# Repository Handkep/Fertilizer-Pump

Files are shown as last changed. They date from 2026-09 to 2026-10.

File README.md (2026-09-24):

# Automatic Fertilizer Dispenser

The fertilizer dispenser automatically doses fertilizer concentrates or stock solutions using one or more peristaltic pumps. The amount dispensed depends on the selected recipe and the intended irrigation water volume. After dosing, the pump and outlet tubing are flushed with water to help prevent salt deposits.

**Project status:** In development. The Peristaltic pump is currently in the prototyping phase. PCB design is in progress. The user interface and display are still to be determined.

## How It Works

Each recipe specifies a dose in ml per liter of irrigation water for each fertilizer. The required amount is calculated as follows:

```text
Fertilizer volume [ml] = Water volume [L] × Dose [ml/L]

Example: 10 L of water × 5 ml/L = 50 ml of fertilizer
```

A recipe can contain multiple fertilizers. Each fertilizer has its own separate channel, and the fertilizers are mixed only in the watering can. In the future, the device may support mixing fertilizers, after the pumps, to have a single outlet for the mixed solution. 

## Operation

The planned interface consists of a display and a rotary encoder with a push button:

1. **Set the water volume:** Turn the knob. Each detent increases the selected volume by 1 L.
2. **Confirm the volume:** Press the knob to proceed to recipe selection.
3. **Select a recipe:** Turn the knob to choose the desired recipe.
4. **Start dosing:** Press the knob again to dispense the fertilizer.

the further interface planning is still in progress. The display type has not yet been selected.

## Hardware

| Component | Planned configuration |
| --- | --- |
| Controller | ESP32-S3 |
| Channels | Four positions, initially only two populated with TMC2209 modules |
| Motor drivers | Plug-in TMC2209 StepStick modules |
| Driver control | STEP/DIR/EN and UART |
| Pumps | Custom stepper-driven peristaltic pumps, designed in Onshape |
| Motors | NEMA17 stepper motors |
| User interface | Rotary encoder with push button and a display |
| Display | To be selected: a small OLED or another display type; no seven-segment display |
| Calibration | Individual steps-per-ml calibration for each pump |

## Power and USB

### V1

- Motor and solenoid valve operation requires USB-C PD or a separate 12 V power supply.
- USB-C provides data connectivity and firmware flashing.
- USB alone is intended to power the control electronics, including the ESP32-S3 and user interface. Motors and solenoid valves remain inactive without the 12 V supply. The 12 V supply should not be required for firmware flashing.
- USB Power Delivery is included in V1.

## Fluid Path and Flushing

Each fertilizer channel has a selector valve upstream of the pump:

```mermaid
flowchart LR
    fertilizer["Fertilizer concentrate<br/>or stock solution"] -->|Dosing| valve{"Selector valve"}
    water["Flush water"] -->|Flushing| valve
    valve --> pump(["Peristaltic pump"])
    pump -->|Outlet tubing| can["Watering can"]

    classDef fertilizerStyle fill:#dcfce7,stroke:#15803d,color:#14532d,stroke-width:2px;
    classDef waterStyle fill:#dbeafe,stroke:#2563eb,color:#1e3a8a,stroke-width:2px;
    classDef hardwareStyle fill:#f1f5f9,stroke:#64748b,color:#0f172a,stroke-width:2px;
    classDef outputStyle fill:#fef3c7,stroke:#d97706,color:#78350f,stroke-width:2px;

    class fertilizer fertilizerStyle;
    class water waterStyle;
    class valve,pump hardwareStyle;
    class can outputStyle;
    linkStyle 0 stroke:#15803d,stroke-width:2px;
    linkStyle 1 stroke:#2563eb,stroke-width:2px;
```

V1 will initially use an inexpensive electrically operated two-position solenoid selector valve.

After dosing, the valve switches to water to flush the pump and outlet tubing. The flushing water also flows into the watering can.

The additional flushing water is not included in the fertilizer dose calculation. For the intended use, this extra volume is considered small relative to the uncertainty of measuring the water volume in a watering can.

### Planned for V2

- "peristaltic" selector valve built out of a servo and a 3D-printed part.
    - The servo connector will already be included on the V1 PCB to simplify this future upgrade.

## Development Status

The operating concept, four channel positions with two initially populated motor drivers, and separate fertilizer paths have been defined.

Practical testing is still pending. The display has not yet been selected.

## Future Possibilities

- Release as an open-source project
- A PCB kit or complete DIY kit
- Accompanying project documentation on YouTube

## License

A license has not yet been selected.

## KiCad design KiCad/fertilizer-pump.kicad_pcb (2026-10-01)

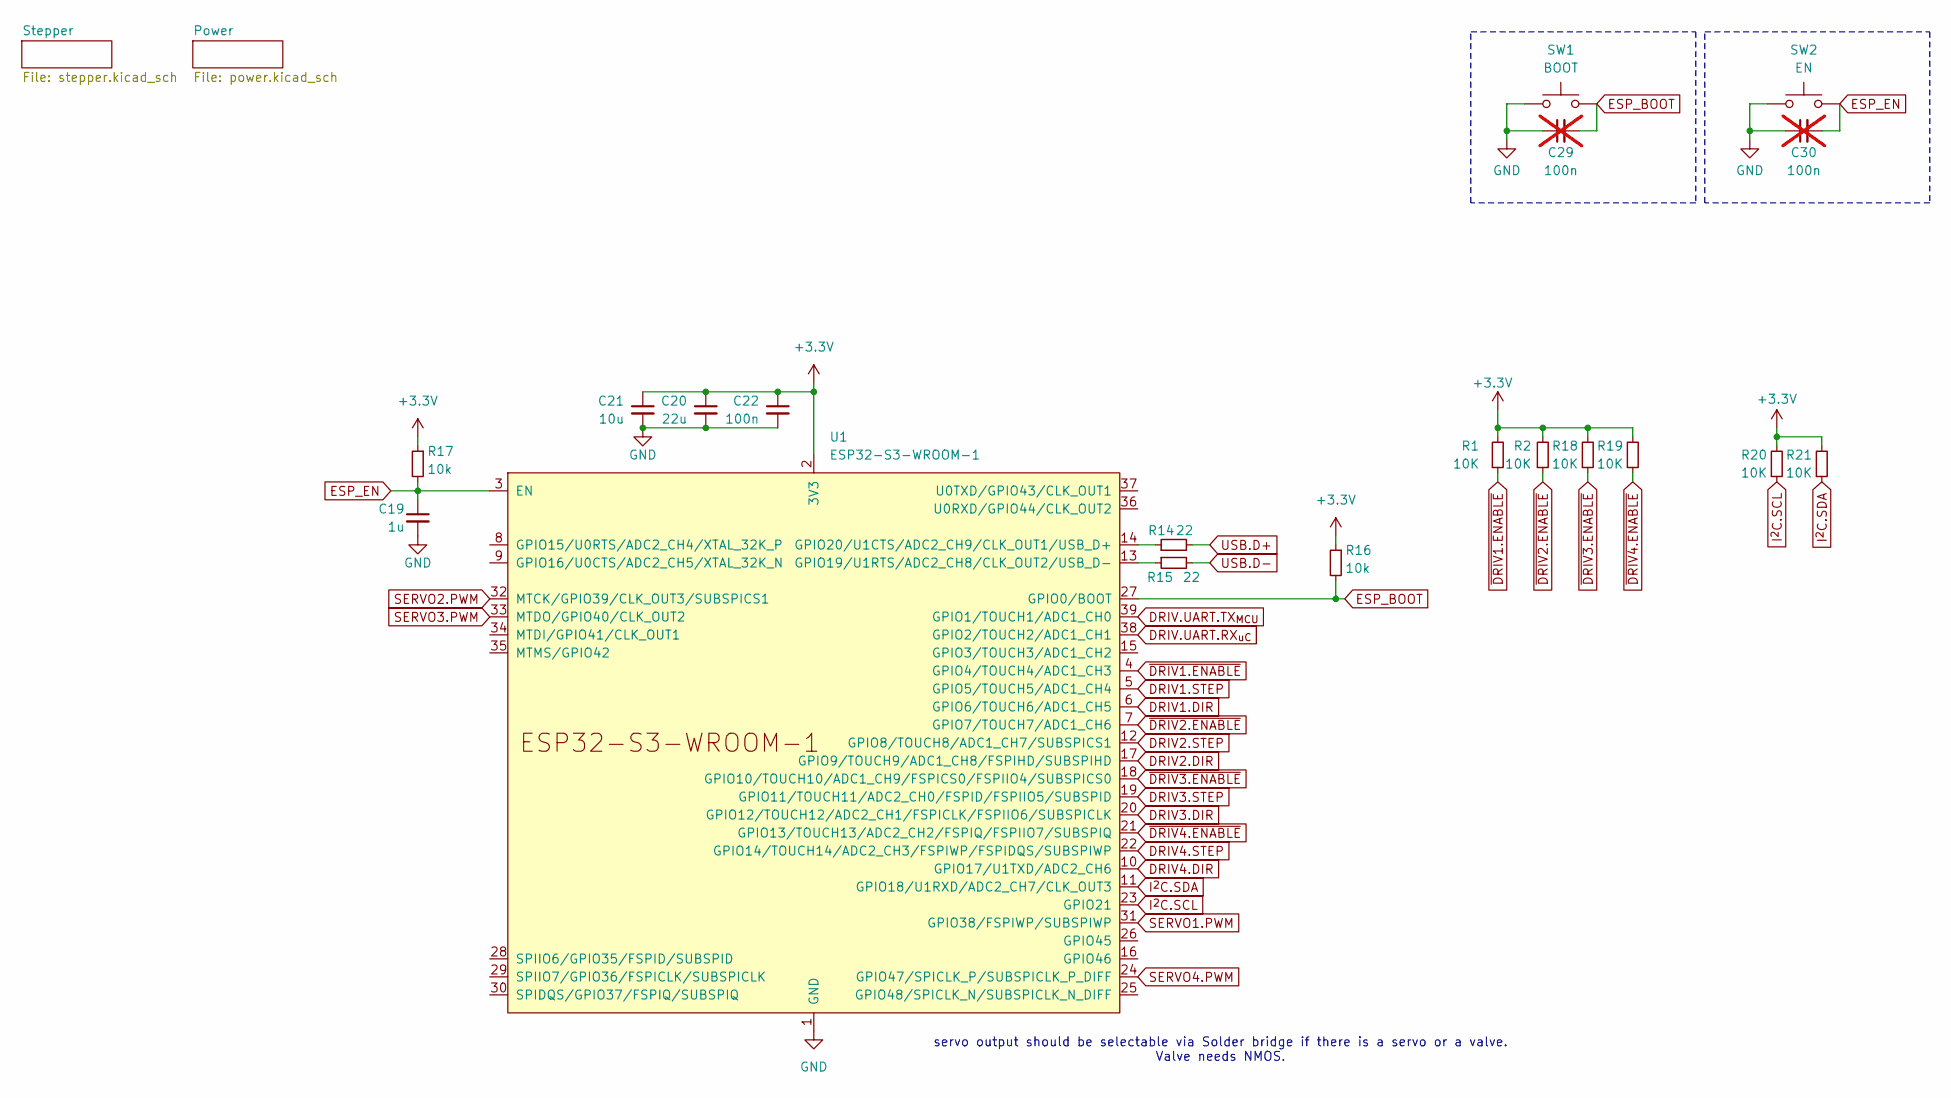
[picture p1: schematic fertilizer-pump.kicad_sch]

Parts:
C19: 1u; C_0805_2012Metric_Pad1.18x1.45mm_HandSolder; LCSC C303896
C20: 22u; C_0805_2012Metric_Pad1.18x1.45mm_HandSolder; LCSC C7432777
C21: 10u; C_0805_2012Metric_Pad1.18x1.45mm_HandSolder; LCSC C33546007
C22: 100n; C_0805_2012Metric_Pad1.18x1.45mm_HandSolder; LCSC C5137467
C29, C30: 100n; C_0805_2012Metric_Pad1.18x1.45mm_HandSolder; LCSC C5137467; not fitted
R1, R2, R18, R19, R20, R21: 10K; R_0805_2012Metric_Pad1.20x1.40mm_HandSolder; LCSC C2930231
R14, R15: 22; R_0805_2012Metric_Pad1.20x1.40mm_HandSolder
R16, R17: 10k; R_0805_2012Metric_Pad1.20x1.40mm_HandSolder; LCSC C2930231
SW1: BOOT; SHOU HAN TS342A2P-WZ; LCSC C557591
SW2: EN; SHOU HAN TS342A2P-WZ; LCSC C557591
U1: ESP32-S3-WROOM-1

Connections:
+3.3V: C20.1, C21.1, C22.1, R1.2, R2.2, R16.1, R17.1, R18.2, R19.2, R20.2, R21.2, U1.2 (3V3); also elsewhere on the board
DRIV1.DIR: U1.6 (GPIO6/TOUCH6/ADC1_CH5); also elsewhere on the board
DRIV1.STEP: U1.5 (GPIO5/TOUCH5/ADC1_CH4); also elsewhere on the board
DRIV2.DIR: U1.17 (GPIO9/TOUCH9/ADC1_CH8/FSPIHD/SUBSPIHD); also elsewhere on the board
DRIV2.STEP: U1.12 (GPIO8/TOUCH8/ADC1_CH7/SUBSPICS1); also elsewhere on the board
DRIV3.DIR: U1.20 (GPIO12/TOUCH12/ADC2_CH1/FSPICLK/FSPIIO6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); also elsewhere on the board
DRIV3.STEP: U1.19 (GPIO11/TOUCH11/ADC2_CH0/FSPID/FSPIIO5/S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); also elsewhere on the board
DRIV4.DIR: U1.10 (GPIO17/U1TXD/ADC2_CH6); also elsewhere on the board
DRIV4.STEP: U1.22 (GPIO14/TOUCH14/ADC2_CH3/FSPIWP/FSPIDQS/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); also elsewhere on the board
DRIV.UART: U1.38 (GPIO2/TOUCH2/ADC1_CH1); also elsewhere on the board
DRIV.UART.TX_{MCU}: U1.39 (GPIO1/TOUCH1/ADC1_CH0); also elsewhere on the board
ESP_BOOT: C29.2, R16.2, SW1.2, U1.27 (GPIO0/BOOT)
ESP_EN: C19.1, C30.2, R17.2, SW2.2, U1.3 (EN)
GND: C19.2, C20.2, C21.2, C22.2, C29.1, C30.1, SW1.1, SW2.1, U1.1 (GND), U1.40 (GND), U1.41 (GND); also elsewhere on the board
I^{2}C.SCL: R20.1, U1.23 (GPIO21); also elsewhere on the board
I^{2}C.SDA: R21.1, U1.11 (GPIO18/U1RXD/ADC2_CH7/CLK_OUT3); also elsewhere on the board
unnamed: R15.1, U1.13 (GPIO19/U1RTS/ADC2_CH8/CLK_OUT2/USB_D-)
unnamed: R14.1, U1.14 (GPIO20/U1CTS/ADC2_CH9/CLK_OUT1/USB_D+)
SERVO1.PWM: U1.31 (GPIO38/FSPIWP/SUBSPIWP); also elsewhere on the board
SERVO2.PWM: U1.32 (MTCK/GPIO39/CLK_OUT3/SUBSPICS1); also elsewhere on the board
SERVO3.PWM: U1.33 (MTDO/GPIO40/CLK_OUT2); also elsewhere on the board
SERVO4.PWM: U1.24 (GPIO47/SPICLK_P/SUBSPICLK_P_DIFF); also elsewhere on the board
USB.D+: R14.2; also elsewhere on the board
USB.D-: R15.2; also elsewhere on the board
~DRIV1.ENABLE: R1.1, U1.4 (GPIO4/TOUCH4/ADC1_CH3); also elsewhere on the board
~DRIV2.ENABLE: R2.1, U1.7 (GPIO7/TOUCH7/ADC1_CH6); also elsewhere on the board
~DRIV3.ENABLE: R18.1, U1.18 (GPIO10/TOUCH10/ADC1_CH9/FSPICS0/FSPIIO4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); also elsewhere on the board
~DRIV4.ENABLE: R19.1, U1.21 (GPIO13/TOUCH13/ADC2_CH2/FSPIQ/FSPIIO7/S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); also elsewhere on the board

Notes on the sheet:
servo output should be selectable via Solder bridge if there is a servo or a valve. Valve needs NMOS.

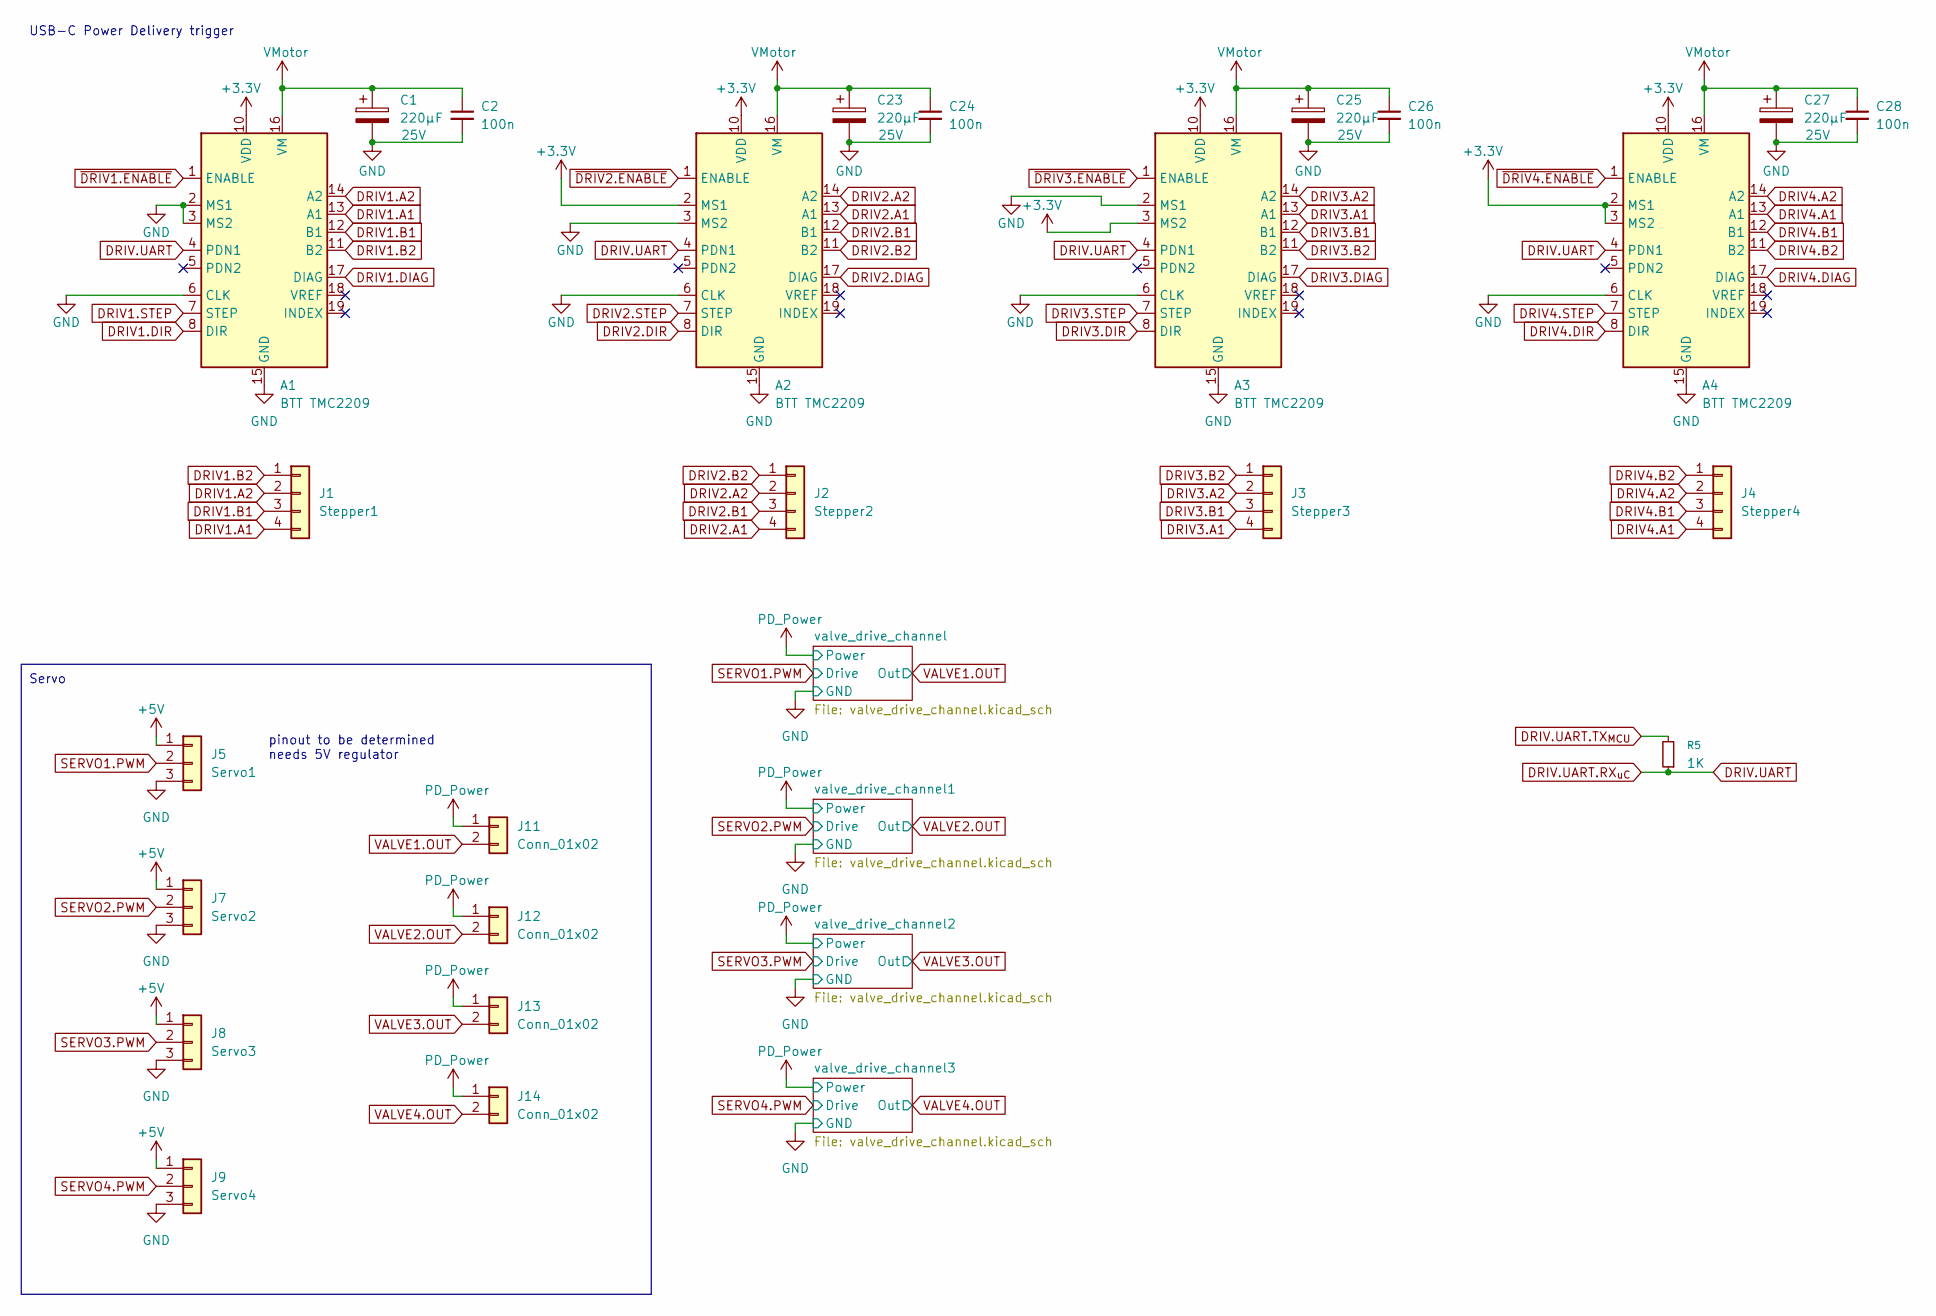
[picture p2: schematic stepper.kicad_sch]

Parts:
A1, A2, A3, A4: BTT TMC2209
C1, C23, C25, C27: 220µF; CP_Elec_6.3x7.7; Voltage 25V; LCSC C7471881
C2, C24, C26, C28: 100n; C_0805_2012Metric_Pad1.18x1.45mm_HandSolder; LCSC C48579601
J1: Stepper1; JST_XH_B4B-XH-A_1x04_P2.50mm_Vertical
J2: Stepper2; JST_XH_B4B-XH-A_1x04_P2.50mm_Vertical
J3: Stepper3; JST_XH_B4B-XH-A_1x04_P2.50mm_Vertical
J4: Stepper4; JST_XH_B4B-XH-A_1x04_P2.50mm_Vertical
J5: Servo1; JST_XH_B3B-XH-A_1x03_P2.50mm_Vertical
J7: Servo2; JST_XH_B3B-XH-A_1x03_P2.50mm_Vertical
J8: Servo3; JST_XH_B3B-XH-A_1x03_P2.50mm_Vertical
J9: Servo4; JST_XH_B3B-XH-A_1x03_P2.50mm_Vertical
J11, J12, J13, J14: Conn_01x02; JST_XH_B2B-XH-A_1x02_P2.50mm_Vertical
R5: 1K; R_0805_2012Metric_Pad1.20x1.40mm_HandSolder; LCSC C54921120

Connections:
+3.3V: A1.10 (VDD), A2.2 (MS1), A2.10 (VDD), A3.3 (MS2), A3.10 (VDD), A4.2 (MS1), A4.3 (MS2), A4.10 (VDD); also elsewhere on the board
+5V: J5.1, J7.1, J8.1, J9.1; also elsewhere on the board
DRIV1.A1: A1.13 (A1), J1.4
DRIV1.A2: A1.14 (A2), J1.2
DRIV1.B1: A1.12 (B1), J1.3
DRIV1.B2: A1.11 (B2), J1.1
DRIV1.DIAG: A1.17 (DIAG)
DRIV1.DIR: A1.8 (DIR); also elsewhere on the board
DRIV1.STEP: A1.7 (STEP); also elsewhere on the board
DRIV2.A1: A2.13 (A1), J2.4
DRIV2.A2: A2.14 (A2), J2.2
DRIV2.B1: A2.12 (B1), J2.3
DRIV2.B2: A2.11 (B2), J2.1
DRIV2.DIAG: A2.17 (DIAG)
DRIV2.DIR: A2.8 (DIR); also elsewhere on the board
DRIV2.STEP: A2.7 (STEP); also elsewhere on the board
DRIV3.A1: A3.13 (A1), J3.4
DRIV3.A2: A3.14 (A2), J3.2
DRIV3.B1: A3.12 (B1), J3.3
DRIV3.B2: A3.11 (B2), J3.1
DRIV3.DIAG: A3.17 (DIAG)
DRIV3.DIR: A3.8 (DIR); also elsewhere on the board
DRIV3.STEP: A3.7 (STEP); also elsewhere on the board
DRIV4.A1: A4.13 (A1), J4.4
DRIV4.A2: A4.14 (A2), J4.2
DRIV4.B1: A4.12 (B1), J4.3
DRIV4.B2: A4.11 (B2), J4.1
DRIV4.DIAG: A4.17 (DIAG)
DRIV4.DIR: A4.8 (DIR); also elsewhere on the board
DRIV4.STEP: A4.7 (STEP); also elsewhere on the board
DRIV.UART: A1.4 (PDN1), A2.4 (PDN1), A3.4 (PDN1), A4.4 (PDN1), R5.1; also elsewhere on the board
DRIV.UART.TX_{MCU}: R5.2; also elsewhere on the board
GND: A1.2 (MS1), A1.3 (MS2), A1.6 (CLK), A1.9 (GND), A1.15 (GND), A2.3 (MS2), A2.6 (CLK), A2.9 (GND), A2.15 (GND), A3.2 (MS1), A3.6 (CLK), A3.9 (GND), A3.15 (GND), A4.6 (CLK), A4.9 (GND), A4.15 (GND), C1.2, C2.2, C23.2, C24.2, C25.2, C26.2, C27.2, C28.2, J5.3, J7.3, J8.3, J9.3; also elsewhere on the board
PD_Power: J11.1, J12.1, J13.1, J14.1; also elsewhere on the board
SERVO1.PWM: J5.2; also elsewhere on the board
SERVO2.PWM: J7.2; also elsewhere on the board
SERVO3.PWM: J8.2; also elsewhere on the board
SERVO4.PWM: J9.2; also elsewhere on the board
VALVE1.OUT: J11.2; also elsewhere on the board
VALVE2.OUT: J12.2; also elsewhere on the board
VALVE3.OUT: J13.2; also elsewhere on the board
VALVE4.OUT: J14.2; also elsewhere on the board
VMotor: A1.16 (VM), A2.16 (VM), A3.16 (VM), A4.16 (VM), C1.1, C2.1, C23.1, C24.1, C25.1, C26.1, C27.1, C28.1; also elsewhere on the board
~DRIV1.ENABLE: A1.1 (ENABLE); also elsewhere on the board
~DRIV2.ENABLE: A2.1 (ENABLE); also elsewhere on the board
~DRIV3.ENABLE: A3.1 (ENABLE); also elsewhere on the board
~DRIV4.ENABLE: A4.1 (ENABLE); also elsewhere on the board

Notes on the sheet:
USB-C Power Delivery trigger
Servo
pinout to be determined needs 5V regulator

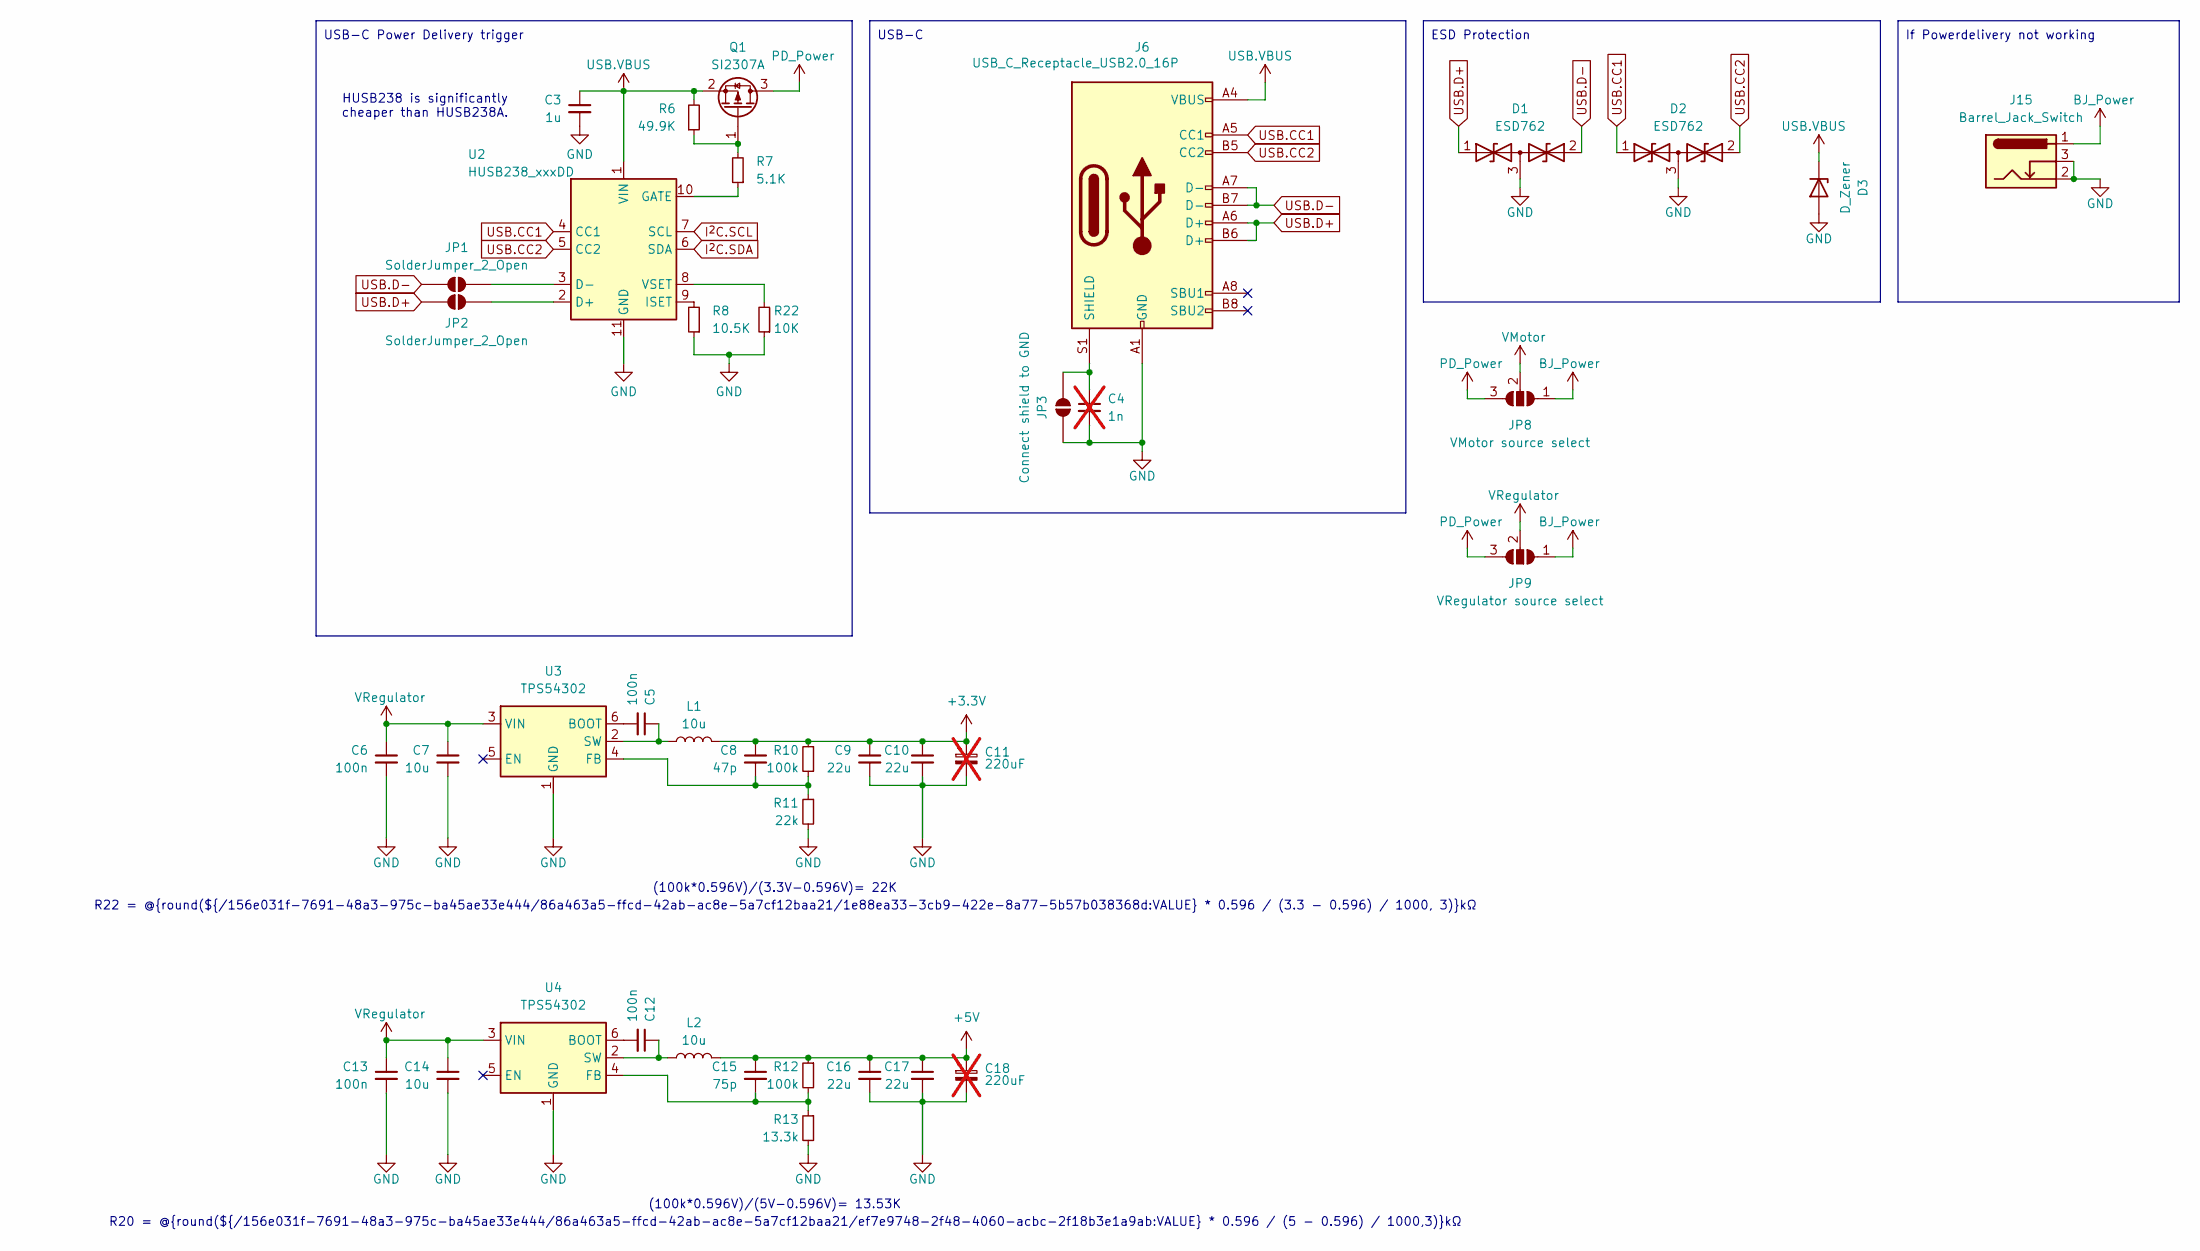
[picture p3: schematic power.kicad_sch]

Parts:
C3: 1u; C_0805_2012Metric_Pad1.18x1.45mm_HandSolder; LCSC C89190
C4: 1n; C_0805_2012Metric_Pad1.18x1.45mm_HandSolder; not fitted
C5, C6, C12, C13: 100n; C_0805_2012Metric_Pad1.18x1.45mm_HandSolder; LCSC C5137467
C7, C14: 10u; C_0805_2012Metric_Pad1.18x1.45mm_HandSolder; LCSC C33546007
C8: 47p; C_0805_2012Metric_Pad1.18x1.45mm_HandSolder; LCSC C5137501
C9, C10, C16, C17: 22u; C_0805_2012Metric_Pad1.18x1.45mm_HandSolder; LCSC C7432777
C11, C18: 220uF; CP_Radial_D8.0mm_P3.50mm; LCSC C107639; not fitted
C15: 75p; C_0805_2012Metric_Pad1.18x1.45mm_HandSolder; LCSC C5360822
D1, D2: ESD762; SOT-23_Handsoldering; LCSC C53340942
D3: D_Zener; D_SOD-123FL; LCSC C353298
J6: USB_C_Receptacle_USB2.0_16P; USB_C_Receptacle_GCT_USB4105-xx-A_16P_TopMnt_Horizontal; LCSC C2765186
J15: Barrel_Jack_Switch; BarrelJack_GCT_DCJ200-10-A_Horizontal; LCSC C22459640
JP1, JP2: SolderJumper_2_Open; SolderJumper-2_P1.3mm_Open_RoundedPad1.0x1.5mm
JP3: Connect shield to GND; SolderJumper-2_P1.3mm_Open_RoundedPad1.0x1.5mm
JP8: VMotor source select; SolderJumper-3_P1.3mm_Open_RoundedPad1.0x1.5mm
JP9: VRegulator source select; SolderJumper-3_P1.3mm_Open_RoundedPad1.0x1.5mm
L1, L2: 10u; L_APV_APH0630; LCSC C5349698
Q1: SI2307A; SOT-23; LCSC C347490
R6: 49.9K; R_0805_2012Metric_Pad1.20x1.40mm_HandSolder; LCSC C2930203
R7: 5.1K; R_0805_2012Metric_Pad1.20x1.40mm_HandSolder; LCSC C118848
R8: 10.5K; R_0805_2012Metric_Pad1.20x1.40mm_HandSolder; LCSC C40086
R10, R12: 100k; R_0603_1608Metric_Pad0.98x0.95mm_HandSolder; LCSC C51048119
R11: 22k; R_0603_1608Metric_Pad0.98x0.95mm_HandSolder; LCSC C54102214
R13: 13.3k; R_0603_1608Metric_Pad0.98x0.95mm_HandSolder; LCSC C858840
R22: 10K; R_0805_2012Metric_Pad1.20x1.40mm_HandSolder; LCSC C2930231
U2: HUSB238_xxxDD; WDFN-10-1EP_3x3mm_P0.5mm_EP1.8x2.5mm_ThermalVias; LCSC C7471904
U3, U4: TPS54302; SOT-23-6; LCSC C311983

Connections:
+3.3V: C8.1, C9.1, C10.1, C11.1, L1.2, R10.1; also elsewhere on the board
+5V: C15.1, C16.1, C17.1, C18.1, L2.2, R12.1; also elsewhere on the board
BJ_Power: J15.1, JP8.1 (A), JP9.1 (A)
GND: C3.2, C4.2, C6.2, C7.2, C9.2, C10.2, C11.2, C13.2, C14.2, C16.2, C17.2, C18.2, D1.3 (common), D2.3 (common), D3.2 (A), J6.A1 (GND), J6.A12 (GND), J6.B1 (GND), J6.B12 (GND), J15.2, J15.3, JP3.1 (A), R8.1, R11.2, R13.2, R22.1, U2.11 (GND), U3.1 (GND), U4.1 (GND); also elsewhere on the board
I^{2}C.SCL: U2.7 (SCL); also elsewhere on the board
I^{2}C.SDA: U2.6 (SDA); also elsewhere on the board
unnamed: C4.1, J6.S1 (SHIELD), JP3.2 (B)
unnamed: JP1.2 (B), U2.3 (D-)
unnamed: JP2.2 (B), U2.2 (D+)
unnamed: Q1.1 (G), R6.1, R7.2
unnamed: R7.1, U2.10 (GATE)
unnamed: R8.2, U2.9 (ISET)
unnamed: R22.2, U2.8 (VSET)
unnamed: C5.2, U3.6 (BOOT)
unnamed: C8.2, R10.2, R11.1, U3.4 (FB)
unnamed: C5.1, L1.1, U3.2 (SW)
unnamed: C12.2, U4.6 (BOOT)
unnamed: C15.2, R12.2, R13.1, U4.4 (FB)
unnamed: C12.1, L2.1, U4.2 (SW)
PD_Power: JP8.3 (B), JP9.3 (B), Q1.3 (D); also elsewhere on the board
USB.CC1: D2.1 (A1), J6.A5 (CC1), U2.4 (CC1)
USB.CC2: D2.2 (A2), J6.B5 (CC2), U2.5 (CC2)
USB.D+: D1.1 (A1), J6.A6 (D+), J6.B6 (D+), JP2.1 (A); also elsewhere on the board
USB.D-: D1.2 (A2), J6.A7 (D-), J6.B7 (D-), JP1.1 (A); also elsewhere on the board
USB.VBUS: C3.1, D3.1 (K), J6.A4 (VBUS), J6.A9 (VBUS), J6.B4 (VBUS), J6.B9 (VBUS), Q1.2 (S), R6.2, U2.1 (VIN)
VMotor: JP8.2 (C); also elsewhere on the board
VRegulator: C6.1, C7.1, C13.1, C14.1, JP9.2 (C), U3.3 (VIN), U4.3 (VIN)

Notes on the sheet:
If Powerdelivery not working
USB-C Power Delivery trigger
ESD Protection
HUSB238 is significantly cheaper than HUSB238A.
R22 = @{round(${/156e031f-7691-48a3-975c-ba45ae33e444/86a463a5-ffcd-42ab-ac8e-5a7cf12baa21/1e88ea33-3cb9-422e-8a77-5b57b038368d:VALUE} * 0.596 / (3.3 - 0.596) / 1000, 3)}kΩ
(100k*0.596V)/(5V-0.596V)= 13.53K
(100k*0.596V)/(3.3V-0.596V)= 22K
USB-C
R20 = @{round(${/156e031f-7691-48a3-975c-ba45ae33e444/86a463a5-ffcd-42ab-ac8e-5a7cf12baa21/ef7e9748-2f48-4060-acbc-2f18b3e1a9ab:VALUE} * 0.596 / (5 - 0.596) / 1000,3)}kΩ

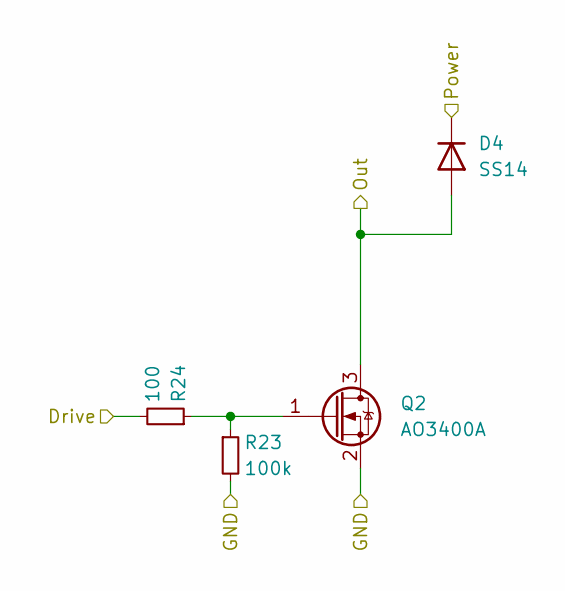
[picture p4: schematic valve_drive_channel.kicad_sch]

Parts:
D4: SS14; D_SMA_Handsoldering; LCSC C2480
Q2: AO3400A; SOT-23; LCSC C347475
R23: 100k; R_0805_2012Metric_Pad1.20x1.40mm_HandSolder; LCSC C3017875
R24: 100; R_0805_2012Metric_Pad1.20x1.40mm_HandSolder; LCSC C2907294

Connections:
GND: Q2.2 (S), R23.2; also elsewhere on the board
unnamed: Q2.1 (G), R23.1, R24.1
PD_Power: D4.1 (K); also elsewhere on the board
SERVO1.PWM: R24.2; also elsewhere on the board
VALVE1.OUT: D4.2 (A), Q2.3 (D); also elsewhere on the board

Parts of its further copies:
D5, D6, D7: SS14; D_SMA_Handsoldering; LCSC C2480
Q3, Q4, Q9: AO3400A; SOT-23; LCSC C347475
R25, R27, R29: 100; R_0805_2012Metric_Pad1.20x1.40mm_HandSolder; LCSC C2907294
R26, R28, R30: 100k; R_0805_2012Metric_Pad1.20x1.40mm_HandSolder; LCSC C3017875

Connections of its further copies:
GND: Q3.2 (S), Q4.2 (S), Q9.2 (S), R26.2, R28.2, R30.2; also elsewhere on the board
unnamed: Q3.1 (G), R25.1, R26.1
unnamed: Q4.1 (G), R27.1, R28.1
unnamed: Q9.1 (G), R29.1, R30.1
PD_Power: D5.1 (K), D6.1 (K), D7.1 (K); also elsewhere on the board
SERVO2.PWM: R25.2; also elsewhere on the board
SERVO3.PWM: R27.2; also elsewhere on the board
SERVO4.PWM: R29.2; also elsewhere on the board
VALVE2.OUT: D5.2 (A), Q3.3 (D); also elsewhere on the board
VALVE3.OUT: D6.2 (A), Q4.3 (D); also elsewhere on the board
VALVE4.OUT: D7.2 (A), Q9.3 (D); also elsewhere on the board

Board: 2 copper layers, 98 parts (0 on the bottom side), 73 nets, no tracks yet.

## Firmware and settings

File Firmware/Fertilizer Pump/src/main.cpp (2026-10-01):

#include <Arduino.h>
#include <AccelStepper.h>
#include <TMCStepper.h>
#include <SoftwareSerial.h>

// --------------------------------------------------
// Zentrale Konfiguration
// Alle Startwerte werden ausschliesslich hier eingestellt.
// --------------------------------------------------

// Serielle Konsole
#define SERIAL_BAUD                       115200UL
#define SERIAL_BUFFER_CAPACITY            64U

// Pins
#define STEP_PIN D2
#define DIR_PIN  D1
#define TMC_RX_PIN D6
#define TMC_TX_PIN D5

// Motor und Bewegung
#define MOTOR_STEP_ANGLE_DEG               1.8f
#define DEFAULT_MICROSTEPS                 8U
#define DEFAULT_MAX_SPEED_RPM              100.0f
#define DEFAULT_ACCELERATION_RPM_PER_S      500.0f
#define DEFAULT_SHOWCASE_RPM               500.0f
#define STEP_MIN_PULSE_US                  2U
#define DEFAULT_DIRECTION_INVERTED         false
#define DEFAULT_STEP_INVERTED              false
#define DEFAULT_ENABLE_INVERTED            false

// TMC2209 UART und Hardware
#define TMC_UART_BAUD                      19200UL
#define DRIVER_ADDRESS                     0b00
#define R_SENSE                            0.11f

// TMC2209 Motorstrom
#define DEFAULT_MOTOR_CURRENT_MA           900U
#define DEFAULT_HOLD_CURRENT_MULTIPLIER    0.30f
#define MIN_MOTOR_CURRENT_MA               100L
#define MAX_MOTOR_CURRENT_MA               2000L

// TMC2209 Chopper und Stromabsenkung
#define DEFAULT_TOFF                       4U
#define DEFAULT_IHOLDDELAY                 8U
#define DEFAULT_TPOWERDOWN                 20U
#define DEFAULT_PDN_UART_ENABLED           true
#define DEFAULT_REGISTER_MICROSTEPS        true
#define DEFAULT_INTERNAL_CURRENT_REFERENCE true
#define DEFAULT_INTERPOLATION              true
#define DEFAULT_SPREADCYCLE                true
#define DEFAULT_PWM_AUTOSCALE              true

// StallGuard; SGTHRS 0 deaktiviert praktisch die Empfindlichkeit.
#define DEFAULT_STALL_THRESHOLD            0U
#define DEFAULT_TCOOLTHRS                  0xFFFFFUL

// Kalibrierung ist nach einem Neustart absichtlich ungesetzt.
#define DEFAULT_STEPS_PER_ML               0.0f


static_assert(DRIVER_ADDRESS <= 3, "DRIVER_ADDRESS muss zwischen 0 und 3 liegen");
static_assert(DEFAULT_HOLD_CURRENT_MULTIPLIER >= 0.0f &&
              DEFAULT_HOLD_CURRENT_MULTIPLIER <= 1.0f,
              "DEFAULT_HOLD_CURRENT_MULTIPLIER muss zwischen 0.0 und 1.0 liegen");
static_assert(DEFAULT_MOTOR_CURRENT_MA >= MIN_MOTOR_CURRENT_MA &&
              DEFAULT_MOTOR_CURRENT_MA <= MAX_MOTOR_CURRENT_MA,
              "DEFAULT_MOTOR_CURRENT_MA liegt ausserhalb der erlaubten Grenzen");
static_assert(DEFAULT_MAX_SPEED_RPM > 0.0f,
              "DEFAULT_MAX_SPEED_RPM muss groesser als 0 sein");
static_assert(DEFAULT_ACCELERATION_RPM_PER_S > 0.0f,
              "DEFAULT_ACCELERATION_RPM_PER_S muss groesser als 0 sein");
static_assert(DEFAULT_SHOWCASE_RPM > 0.0f,
              "DEFAULT_SHOWCASE_RPM muss groesser als 0 sein");
static_assert(MOTOR_STEP_ANGLE_DEG > 0.0f && MOTOR_STEP_ANGLE_DEG <= 360.0f,
              "MOTOR_STEP_ANGLE_DEG muss zwischen 0 und 360 Grad liegen");
static_assert(DEFAULT_TOFF <= 15, "DEFAULT_TOFF muss zwischen 0 und 15 liegen");
static_assert(DEFAULT_IHOLDDELAY <= 15,
              "DEFAULT_IHOLDDELAY muss zwischen 0 und 15 liegen");
static_assert(DEFAULT_TPOWERDOWN <= 255,
              "DEFAULT_TPOWERDOWN muss zwischen 0 und 255 liegen");
static_assert(DEFAULT_STALL_THRESHOLD <= 255,
              "DEFAULT_STALL_THRESHOLD muss zwischen 0 und 255 liegen");
static_assert(DEFAULT_TCOOLTHRS <= 0xFFFFF,
              "DEFAULT_TCOOLTHRS muss ein 20-Bit-Wert sein");
static_assert(DEFAULT_MICROSTEPS == 1 || DEFAULT_MICROSTEPS == 2 ||
              DEFAULT_MICROSTEPS == 4 || DEFAULT_MICROSTEPS == 8 ||
              DEFAULT_MICROSTEPS == 16 || DEFAULT_MICROSTEPS == 32 ||
              DEFAULT_MICROSTEPS == 64 || DEFAULT_MICROSTEPS == 128 ||
              DEFAULT_MICROSTEPS == 256,
              "DEFAULT_MICROSTEPS ist ungueltig");


// --------------------------------------------------
// Stepper
// --------------------------------------------------

SoftwareSerial tmcSerial(TMC_RX_PIN, TMC_TX_PIN);


AccelStepper motor(
    AccelStepper::DRIVER,
    STEP_PIN,
    DIR_PIN
);


TMC2209Stepper driver(
    &tmcSerial,
    R_SENSE,
    DRIVER_ADDRESS
);

// --------------------------------------------------
// Einstellungen
// --------------------------------------------------

uint16_t microstepsSetting = DEFAULT_MICROSTEPS;
uint16_t motorCurrentMaSetting = DEFAULT_MOTOR_CURRENT_MA;
uint8_t stallThresholdSetting = DEFAULT_STALL_THRESHOLD;
bool spreadCycleSetting = DEFAULT_SPREADCYCLE;

// Wird durch CAL gesetzt
float stepsPerMl = DEFAULT_STEPS_PER_ML;

// Letzte gefahrene Schrittzahl für Kalibrierung
long lastMoveSteps = 0;

// Serial-Eingabepuffer
String serialBuffer = "";


// --------------------------------------------------
// Showcase
// --------------------------------------------------

bool showcaseMode = false;

// Laufzeitwerte starten mit den zentral definierten Standardwerten und
// können danach über die seriellen Befehle geändert werden.
float maxSpeedRpm = DEFAULT_MAX_SPEED_RPM;
float accelerationRpmPerSecond = DEFAULT_ACCELERATION_RPM_PER_S;
float showcaseRpm = DEFAULT_SHOWCASE_RPM;


long fullStepsPerRevolution()
{
    return lroundf(360.0f / MOTOR_STEP_ANGLE_DEG);
}


long stepsPerRevolution()
{
    return fullStepsPerRevolution() * (long)microstepsSetting;
}


float rpmToStepsPerSecond(float rpm)
{
    return rpm * stepsPerRevolution() / 60.0f;
}


float stepsPerSecondToRpm(float stepsPerSecond)
{
    return stepsPerSecond * 60.0f / stepsPerRevolution();
}


bool isValidMicrostepSetting(uint16_t microsteps)
{
    return microsteps == 1 || microsteps == 2 || microsteps == 4 ||
           microsteps == 8 || microsteps == 16 || microsteps == 32 ||
           microsteps == 64 || microsteps == 128 || microsteps == 256;
}


bool motorIsRunning()
{
    return showcaseMode || motor.distanceToGo() != 0;
}


// Schreibt immer den vollständigen gewünschten Zustand. Dadurch werden
// auch Register wiederhergestellt, die der TMC2209 bei einem Reset verliert.
uint8_t applyAllDriverSettings()
{
    driver.pdn_disable(DEFAULT_PDN_UART_ENABLED);
    driver.mstep_reg_select(DEFAULT_REGISTER_MICROSTEPS);
    driver.I_scale_analog(!DEFAULT_INTERNAL_CURRENT_REFERENCE);

    driver.toff(DEFAULT_TOFF);
    driver.rms_current(motorCurrentMaSetting,
                       DEFAULT_HOLD_CURRENT_MULTIPLIER);
    driver.iholddelay(DEFAULT_IHOLDDELAY);
    driver.TPOWERDOWN(DEFAULT_TPOWERDOWN);

    driver.microsteps(microstepsSetting);
    driver.intpol(DEFAULT_INTERPOLATION);

    driver.en_spreadCycle(spreadCycleSetting);
    driver.pwm_autoscale(DEFAULT_PWM_AUTOSCALE);

    driver.SGTHRS(stallThresholdSetting);
    driver.TCOOLTHRS(DEFAULT_TCOOLTHRS);

    return driver.test_connection();
}


bool restoreDriverSettings()
{
    uint8_t result = applyAllDriverSettings();

    if (result == 0)
    {
        return true;
    }

    Serial.print("TMC2209 nicht erreichbar, Aktion abgebrochen (Fehler ");
    Serial.print(result);
    Serial.println(")");
    return false;
}


// --------------------------------------------------
// Bewegung starten
// --------------------------------------------------

void moveSteps(long steps)
{
    // Vor jeder Bewegung alle flüchtigen TMC2209-Register neu schreiben.
    if (!restoreDriverSettings())
    {
        return;
    }

    // Showcase beenden
    showcaseMode = false;

    lastMoveSteps = abs(steps);

    motor.move(steps);

    Serial.print("Fahre ");
    Serial.print(steps);
    Serial.println(" Steps");
}


// --------------------------------------------------
// Befehl verarbeiten
// --------------------------------------------------

void processCommand(String command)
{
    command.trim();

    // ==================================================
    // REV <Umdrehungen>
    // ==================================================

    if (command.startsWith("REV "))
    {
        float rev = command.substring(4).toFloat();

        long steps = round(rev * stepsPerRevolution());

        moveSteps(steps);
    }


    // ==================================================
    // MOVE <Steps>
    // ==================================================

    else if (command.startsWith("MOVE "))
    {
        long steps = command.substring(5).toInt();

        moveSteps(steps);
    }


    // ==================================================
    // CAL <gemessene ml>
    // ==================================================

    else if (command.startsWith("CAL "))
    {
        if (motorIsRunning())
        {
            Serial.println("Kalibrierung nur bei stillstehendem Motor speichern");
            return;
        }

        float ml = command.substring(4).toFloat();

        if (ml <= 0)
        {
            Serial.println("Ungueltiger Messwert");
            return;
        }

        if (lastMoveSteps == 0)
        {
            Serial.println("Noch keine Kalibrierfahrt gemacht");
            return;
        }

        stepsPerMl = (float)lastMoveSteps / ml;

        if (!restoreDriverSettings())
        {
            return;
        }

        Serial.println();
        Serial.println("Kalibrierung gespeichert:");

        Serial.print("  Steps: ");
        Serial.println(lastMoveSteps);

        Serial.print("  Volumen: ");
        Serial.print(ml, 3);
        Serial.println(" ml");

        Serial.print("  Steps/ml: ");
        Serial.println(stepsPerMl, 3);

        Serial.print("  ml/Umdrehung: ");
        Serial.println(stepsPerRevolution() / stepsPerMl, 3);

        Serial.println();
    }


    // ==================================================
    // DOSE <ml>
    // ==================================================

    else if (command.startsWith("DOSE "))
    {
        if (stepsPerMl <= 0)
        {
            Serial.println("Zuerst kalibrieren!");
            return;
        }

        float ml = command.substring(5).toFloat();

        if (ml <= 0)
        {
            Serial.println("Ungueltige Menge");
            return;
        }

        long steps = round(ml * stepsPerMl);

        Serial.print("Dosiere ");
        Serial.print(ml, 3);
        Serial.print(" ml -> ");
        Serial.print(steps);
        Serial.println(" Steps");

        moveSteps(steps*-1);
    }


    // ==================================================
    // SPEED <rpm>
    // ==================================================

    else if (command.startsWith("SPEED "))
    {
        if (motorIsRunning())
        {
            Serial.println("Drehzahl nur bei stillstehendem Motor aendern");
            return;
        }

        float rpm = command.substring(6).toFloat();

        if (rpm <= 0)
        {
            Serial.println("Drehzahl muss > 0 RPM sein");
            return;
        }

        maxSpeedRpm = rpm;
        motor.setMaxSpeed(rpmToStepsPerSecond(maxSpeedRpm));

        if (!restoreDriverSettings())
        {
            return;
        }

        Serial.print("Maximale Drehzahl: ");
        Serial.print(maxSpeedRpm, 3);
        Serial.println(" RPM");
    }


    // ==================================================
    // ACCEL <rpm/s^2>
    // ==================================================

    else if (command.startsWith("ACCEL "))
    {
        if (motorIsRunning())
        {
            Serial.println("Beschleunigung nur bei stillstehendem Motor aendern");
            return;
        }

        float acceleration = command.substring(6).toFloat();

        if (acceleration <= 0)
        {
            Serial.println("Beschleunigung muss > 0 RPM/s^2 sein");
            return;
        }

        accelerationRpmPerSecond = acceleration;
        motor.setAcceleration(rpmToStepsPerSecond(accelerationRpmPerSecond));

        if (!restoreDriverSettings())
        {
            return;
        }

        Serial.print("Beschleunigung: ");
        Serial.print(accelerationRpmPerSecond, 3);
        Serial.println(" RPM/s^2");
    }


    // ==================================================
    // CURRENT <mA RMS>
    // ==================================================

    else if (command.startsWith("CURRENT "))
    {
        if (motorIsRunning())
        {
            Serial.println("Motorstrom nur bei stillstehendem Motor aendern");
            return;
        }

        long current = command.substring(8).toInt();

        if (current < MIN_MOTOR_CURRENT_MA || current > MAX_MOTOR_CURRENT_MA)
        {
            Serial.print("Motorstrom muss zwischen ");
            Serial.print(MIN_MOTOR_CURRENT_MA);
            Serial.print(" und ");
            Serial.print(MAX_MOTOR_CURRENT_MA);
            Serial.println(" mA RMS liegen");
            return;
        }

        motorCurrentMaSetting = (uint16_t)current;

        if (!restoreDriverSettings())
        {
            return;
        }

        Serial.print("Motorstrom: ");
        Serial.print(driver.rms_current());
        Serial.print(" mA RMS, Haltestrom ");
        Serial.print(DEFAULT_HOLD_CURRENT_MULTIPLIER * 100.0f, 0);
        Serial.println(" %");
    }


    // ==================================================
    // MICROSTEPS <1|2|4|8|16|32|64|128|256>
    // ==================================================

    else if (command.startsWith("MICROSTEPS "))
    {
        if (motorIsRunning())
        {
            Serial.println("Microsteps nur bei stillstehendem Motor aendern");
            return;
        }

        uint16_t microsteps = (uint16_t)command.substring(11).toInt();

        if (!isValidMicrostepSetting(microsteps))
        {
            Serial.println("Erlaubt: 1, 2, 4, 8, 16, 32, 64, 128 oder 256");
            return;
        }

        microstepsSetting = microsteps;

        // Eine Kalibrierung mit anderer Schrittweite ist sofort ungueltig,
        // auch wenn die anschliessende UART-Uebertragung fehlschlaegt.
        stepsPerMl = DEFAULT_STEPS_PER_ML;

        // Mechanische Drehzahl und Beschleunigung trotz geänderter
        // Schrittweite konstant halten.
        motor.setMaxSpeed(rpmToStepsPerSecond(maxSpeedRpm));
        motor.setAcceleration(rpmToStepsPerSecond(accelerationRpmPerSecond));

        if (!restoreDriverSettings())
        {
            return;
        }

        Serial.print("Microsteps: ");
        Serial.println(microstepsSetting);
        Serial.print("Steps/Umdrehung: ");
        Serial.println(stepsPerRevolution());
        Serial.println("Kalibrierung wurde zurueckgesetzt");
    }


    // ==================================================
    // MODE <STEALTH|SPREAD>
    // ==================================================

    else if (command == "MODE STEALTH")
    {
        if (motorIsRunning())
        {
            Serial.println("Treiber-Modus nur bei stillstehendem Motor aendern");
            return;
        }

        spreadCycleSetting = false;

        if (!restoreDriverSettings())
        {
            return;
        }

        Serial.println("Modus: StealthChop (leise)");
    }

    else if (command == "MODE SPREAD")
    {
        if (motorIsRunning())
        {
            Serial.println("Treiber-Modus nur bei stillstehendem Motor aendern");
            return;
        }

        spreadCycleSetting = true;

        if (!restoreDriverSettings())
        {
            return;
        }

        Serial.println("Modus: SpreadCycle (mehr Drehmoment)");
    }


    // ==================================================
    // STALL <0..255>
    // ==================================================

    else if (command.startsWith("STALL "))
    {
        if (motorIsRunning())
        {
            Serial.println("StallGuard nur bei stillstehendem Motor einstellen");
            return;
        }

        long threshold = command.substring(6).toInt();

        if (threshold < 0 || threshold > 255)
        {
            Serial.println("StallGuard-Schwellwert muss zwischen 0 und 255 liegen");
            return;
        }

        stallThresholdSetting = (uint8_t)threshold;

        if (!restoreDriverSettings())
        {
            return;
        }

        Serial.print("StallGuard-Schwellwert: ");
        Serial.println(threshold);
        Serial.println("Fuer StallGuard MODE SPREAD verwenden");
    }


    // ==================================================
    // SHOWCASE [rpm]
    //
    // SHOWCASE
    // SHOWCASE 20
    // SHOWCASE -20
    // ==================================================

    else if (command.startsWith("SHOWCASE"))
    {
        // Optional eine Geschwindigkeit mitgeben
        if (command.length() > 8)
        {
            float requestedRpm = command.substring(9).toFloat();

            if (requestedRpm != 0)
            {
                showcaseRpm = requestedRpm;
            }
        }

        // MaxSpeed muss groß genug für runSpeed() sein
        if (abs(showcaseRpm) > maxSpeedRpm)
        {
            maxSpeedRpm = abs(showcaseRpm);
            motor.setMaxSpeed(rpmToStepsPerSecond(maxSpeedRpm));
        }

        // Direkt vor dem Start alle Treiberregister wiederherstellen.
        if (!restoreDriverSettings())
        {
            return;
        }

        showcaseMode = true;

        motor.setSpeed(rpmToStepsPerSecond(showcaseRpm));

        Serial.print("Showcase gestartet mit ");
        Serial.print(showcaseRpm, 3);
        Serial.println(" RPM");

        Serial.println("Mit STOP beenden");
    }


    // ==================================================
    // STOP
    // ==================================================

    else if (command == "STOP")
    {
        if (showcaseMode)
        {
            // Showcase sofort stoppen
            showcaseMode = false;
            motor.setSpeed(0);

            Serial.println("Showcase gestoppt");
        }
        else
        {
            // Normale Bewegung kontrolliert abbremsen
            motor.stop();

            Serial.println("Stop / Abbremsen");
        }
    }


    // ==================================================
    // STATUS
    // ==================================================

    else if (command == "STATUS")
    {
        Serial.println();
        Serial.println("----- STATUS -----");

        Serial.print("Position: ");
        Serial.println(motor.currentPosition());

        Serial.print("Zielposition: ");
        Serial.println(motor.targetPosition());

        Serial.print("Restweg: ");
        Serial.println(motor.distanceToGo());

        Serial.print("Geschwindigkeit: ");
        Serial.print(stepsPerSecondToRpm(motor.speed()), 3);
        Serial.println(" RPM");

        Serial.print("Maximale Drehzahl: ");
        Serial.print(maxSpeedRpm, 3);
        Serial.println(" RPM");

        Serial.print("Beschleunigung: ");
        Serial.print(accelerationRpmPerSecond, 3);
        Serial.println(" RPM/s^2");

        Serial.print("Steps/ml: ");

        if (stepsPerMl > 0)
        {
            Serial.println(stepsPerMl, 3);
        }
        else
        {
            Serial.println("nicht kalibriert");
        }

        Serial.print("Showcase: ");
        Serial.println(showcaseMode ? "AN" : "AUS");

        Serial.println();
        Serial.println("----- TMC2209 -----");

        Serial.print("Chip-Version: 0x");
        Serial.println(driver.version(), HEX);

        Serial.print("UART IFCNT: ");
        Serial.println(driver.IFCNT());

        Serial.print("Motorstrom: ");
        Serial.print(driver.rms_current());
        Serial.println(" mA RMS");

        Serial.print("Haltestrom: ");
        Serial.print(DEFAULT_HOLD_CURRENT_MULTIPLIER * 100.0f, 0);
        Serial.print(" % (ca. ");
        Serial.print(driver.rms_current() * DEFAULT_HOLD_CURRENT_MULTIPLIER, 0);
        Serial.println(" mA RMS)");

        Serial.print("Microsteps: ");
        Serial.println(driver.microsteps());

        Serial.print("Vollschrittwinkel: ");
        Serial.print(MOTOR_STEP_ANGLE_DEG, 3);
        Serial.println(" Grad");

        Serial.print("Vollschritte/Umdrehung: ");
        Serial.println(fullStepsPerRevolution());

        Serial.print("Steps/Umdrehung: ");
        Serial.println(stepsPerRevolution());

        Serial.print("Interpolation: ");
        Serial.println(driver.intpol() ? "AN" : "AUS");

        Serial.print("Treiber-Modus: ");
        Serial.println(driver.en_spreadCycle() ? "SpreadCycle" : "StealthChop");

        Serial.print("TSTEP: ");
        Serial.println(driver.TSTEP());

        Serial.print("SG_RESULT: ");
        Serial.println(driver.SG_RESULT());

        Serial.print("SGTHRS: ");
        Serial.println(driver.SGTHRS());

        Serial.print("TOFF: ");
        Serial.println(driver.toff());

        Serial.print("TPOWERDOWN: ");
        Serial.println(driver.TPOWERDOWN());

        Serial.print("Temperaturwarnung: ");
        Serial.println(driver.otpw() ? "JA" : "nein");
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
void loop()
{
    // --------------------------------------------------
    // Motor bedienen
    // --------------------------------------------------

    if (showcaseMode)
    {
        // Endlos mit konstanter Geschwindigkeit
        motor.runSpeed();
    }
    else
    {
        // Normale Bewegung mit Beschleunigung/Bremsung
        motor.run();
    }


    // --------------------------------------------------
    // Serielle Schnittstelle einlesen
    // --------------------------------------------------

    while (Serial.available())
    {
        char c = Serial.read();

        // Befehl bei Newline ausführen
        if (c == '\n')
        {
            if (serialBuffer.length() > 0)
            {
                processCommand(serialBuffer);
            }

            serialBuffer = "";
        }

        // Carriage Return ignorieren
        else if (c != '\r')
        {
            serialBuffer += c;
        }
    }
}

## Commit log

2026-09-16 first ideas
    [fertilizer-pump.kicad_pcb, fertilizer-pump.kicad_sch]
2026-09-17 Save project baseline before power supply and USB changes
    [fertilizer-pump.kicad_sch]
2026-09-17 add motor connector
    [fertilizer-pump.kicad_sch]
2026-09-23 add pd trigger board, usb-c
    [fertilizer-pump.kicad_sch]
2026-09-25 add buck converter, fix footprints
    [fertilizer-pump.kicad_sch, power.kicad_sch, stepper.kicad_sch]
2026-10-01 add valve driver, many changes
    [fertilizer-pump.kicad_pcb, fertilizer-pump.kicad_sch, power.kicad_sch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]
2026-11-09 update PCB layout and power protection
2026-11-09 compact PCB layout and rearrange components
2026-11-11 add rotary encoder to PCB layout
2026-11-12 add reverse voltage protection
2026-11-13 fix encoder
